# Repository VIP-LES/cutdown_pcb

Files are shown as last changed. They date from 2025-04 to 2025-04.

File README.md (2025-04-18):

# Cutdown PCB – MK5

## Overview

This repository contains the **MK5** revision of the custom PCB used in the Spring 2025 high-altitude balloon cutdown payload. The board integrates all key circuitry for telemetry, sensor data acquisition, LoRa radio communication, and the nichrome-based cutdown system.

Designed and iterated over **11 fabrication runs** (I know, it was painful), this board represents the final, flyable hardware developed using Georgia Tech’s **HIVE** LKPF Protomat and Protolaser systems.

## Fabrication Notes

- **Board Fabrication**: All prototypes were milled and laser-etched in-house using the HIVE’s LPKF Protomat and Protolaser equipment.
- **Inspection**: Due to tooling artifacts, each board required **intense microscope inspection** to manually remove stray micron-level copper bridges using an X-Acto knife and fine probes.
- **Reliability**: The final revision performed successfully in flight, powering the payload and handling cutdown operations as designed.

## Additional Info

The board connects directly to an Adafruit Feather M0 RFM9x and routes power, sensors (MS8607), and nichrome cutdown lines through onboard circuitry. It is designed for compact, modular integration into the balloon payload stack.

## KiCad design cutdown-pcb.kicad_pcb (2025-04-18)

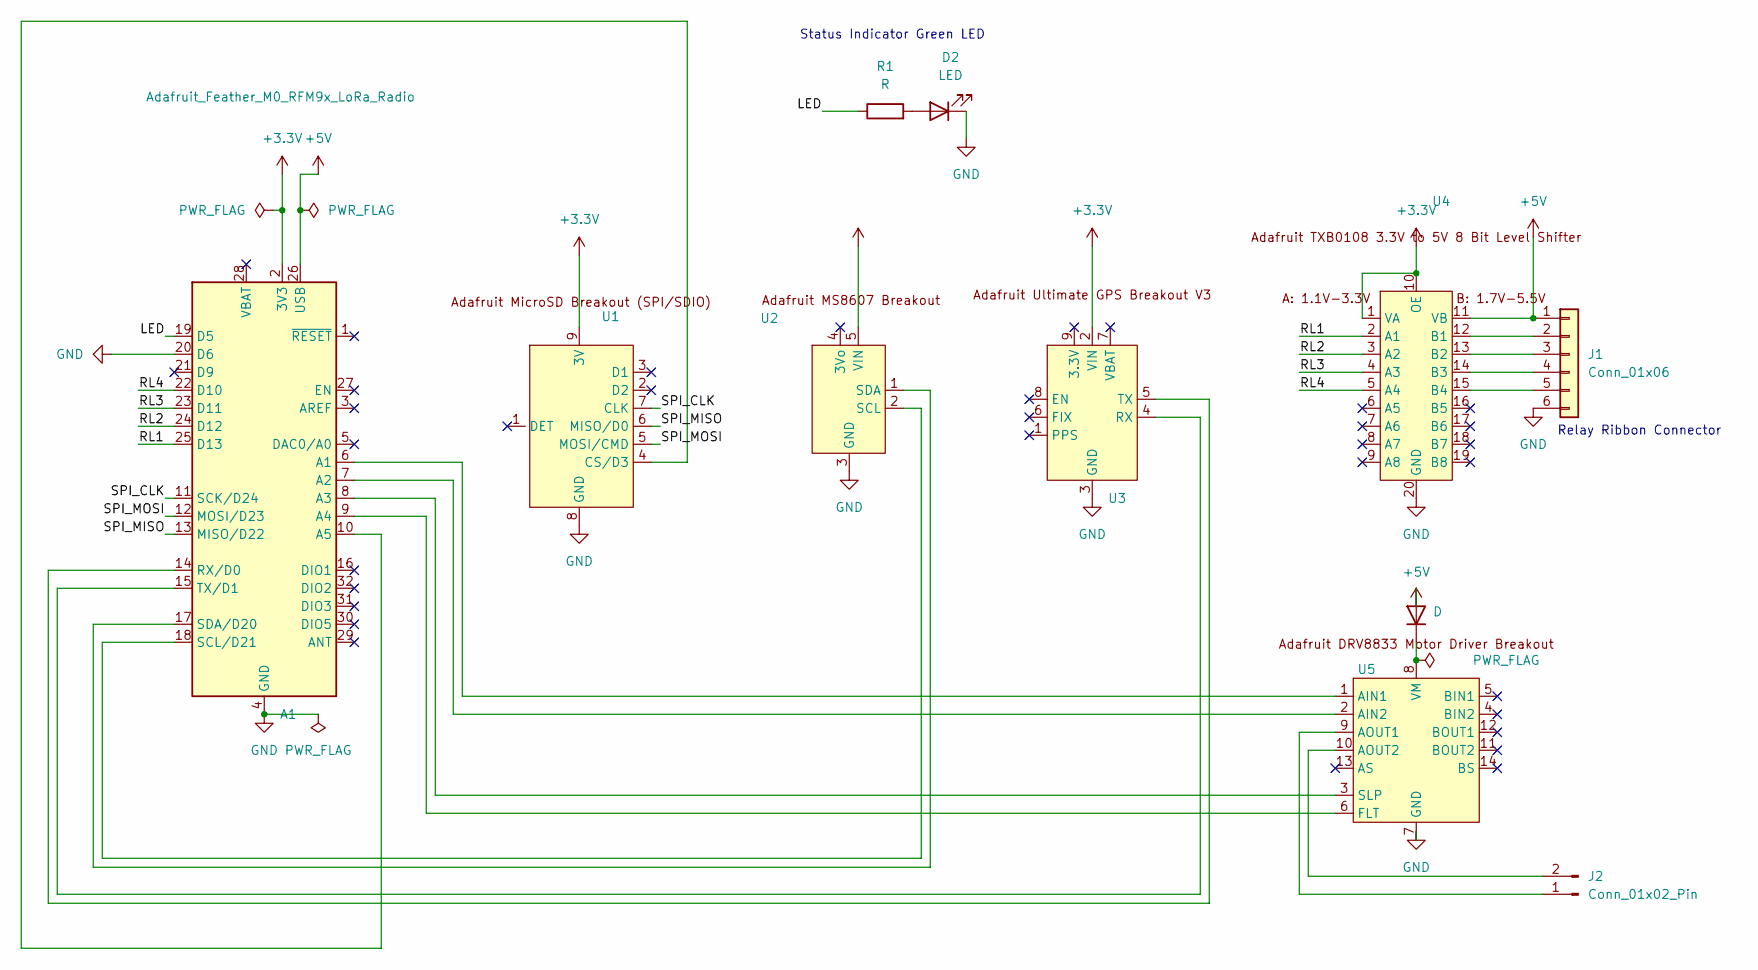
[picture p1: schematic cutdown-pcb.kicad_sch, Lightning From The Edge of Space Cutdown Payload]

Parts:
A1: Adafruit_Feather_M0_RFM9x_LoRa_Radio; Adafruit_Feather_M0_RFM
D1: D; D_DO-35_SOD27_P10.16mm_Horizontal
D2: LED; LED_D5.0mm
J1: Conn_01x06; PinHeader_1x06_P2.54mm_Vertical
J2: Conn_01x02_Pin; PinHeader_1x02_P2.54mm_Vertical
R1: R; R_Axial_DIN0207_L6.3mm_D2.5mm_P10.16mm_Horizontal
U1, U3: PinSocket_1x09_P2.54mm_Vertical
U2: PinSocket_1x05_P2.54mm_Vertical
U4: Adafruit8BitLevelShifter
U5: AdafruitMotorDriverBreakout

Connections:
+3.3V: A1.2 (3V3), U1.9 (3V), U2.5 (VIN), U3.2 (VIN), U4.1 (VA), U4.10 (OE)
+5V: A1.26 (USB), D1.2 (A), J1.1, U4.11 (VB)
/LED: A1.19 (D5), R1.1
/RL1: A1.25 (D13), U4.2 (A1)
/RL2: A1.24 (D12), U4.3 (A2)
/RL3: A1.23 (D11), U4.4 (A3)
/RL4: A1.22 (D10), U4.5 (A4)
/SPI_CLK: A1.11 (SCK/D24), U1.7 (CLK)
/SPI_MISO: A1.13 (MISO/D22), U1.6 (MISO/D0)
/SPI_MOSI: A1.12 (MOSI/D23), U1.5 (MOSI/CMD)
GND: A1.4 (GND), A1.20 (D6), D2.1 (K), J1.6, U1.8 (GND), U2.3 (GND), U3.3 (GND), U4.20 (GND), U5.7 (GND)
unnamed: A1.6 (A1), U5.1 (AIN1)
unnamed: A1.7 (A2), U5.2 (AIN2)
unnamed: A1.8 (A3), U5.3 (SLP)
unnamed: A1.9 (A4), U5.6 (FLT)
unnamed: A1.10 (A5), U1.4 (CS/D3)
unnamed: A1.14 (RX/D0), U3.5 (TX)
unnamed: A1.18 (SCL/D21), U2.2 (SCL)
unnamed: A1.17 (SDA/D20), U2.1 (SDA)
unnamed: A1.15 (TX/D1), U3.4 (RX)
unnamed: D1.1 (K), U5.8 (VM)
unnamed: D2.2 (A), R1.2
unnamed: J1.2, U4.12 (B1)
unnamed: J1.3, U4.13 (B2)
unnamed: J1.4, U4.14 (B3)
unnamed: J1.5, U4.15 (B4)
unnamed: J2.1, U5.9 (AOUT1)
unnamed: J2.2, U5.10 (AOUT2)

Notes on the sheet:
Status Indicator Green LED
Relay Ribbon Connector

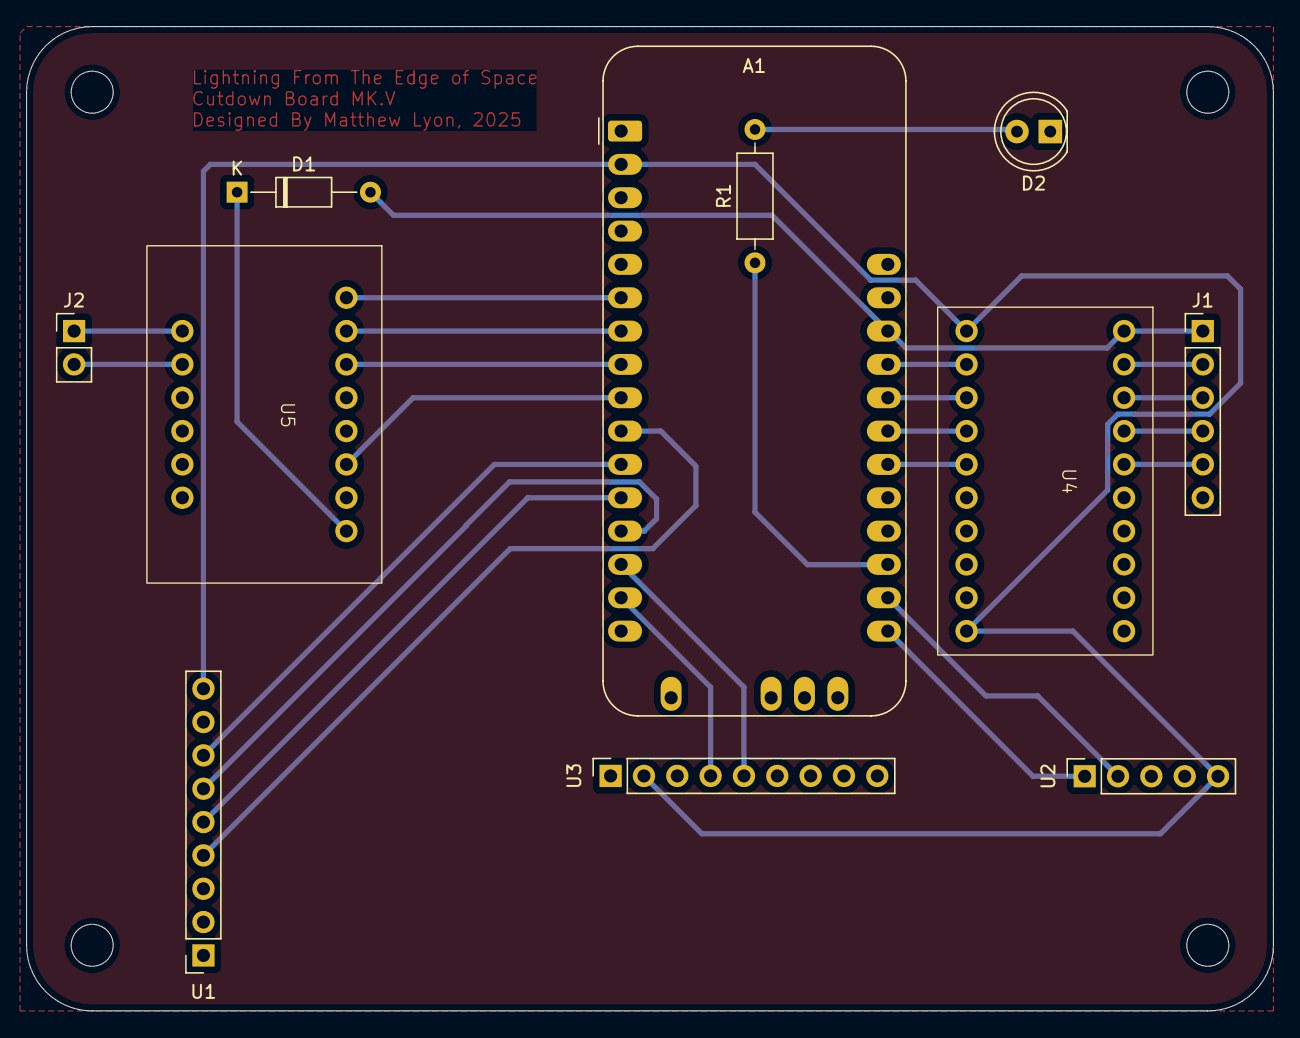
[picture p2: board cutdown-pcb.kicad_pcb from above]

Board: 2 copper layers, 95.0 x 75.0 mm, 11 parts (0 on the bottom side), 28 nets.

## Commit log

2025-04-02 Intial PCB build 1
    [cutdown-pcb.kicad_pcb, cutdown-pcb.kicad_sch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]
2025-04-03 Version 3
    [cutdown-pcb.kicad_pcb, cutdown-pcb.kicad_sch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]
2025-04-18 Final SP '25 Flyable PCB and Cutdown board laser files
    [cutdown-pcb.kicad_pcb, cutdown-pcb.kicad_sch]
